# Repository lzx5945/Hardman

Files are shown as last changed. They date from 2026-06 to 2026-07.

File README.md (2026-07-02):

# Hardman
中国高校智能机器人创意赛主题三—轮式格斗机器人A类

代码以及PCB详情资料请见：https://github.com/lim668568-sketch/Robot_car_battle.git

📖一、总体设计理念

1.1 活动铲构型

采用 活动铲 替代传统固定铲，铲子可在出发时扬起，上台时利用惯性自然下落贴地。

该设计为内部部件（电机、电池、传感器等）释放出更大布置空间，同时保持整车尺寸为 27×29 cm，严格符合 A 类规则（≤30×30 cm）。

1.2 关节摩擦控制

铲臂转动处使用 轴承 + 自锁螺母 组合，精确调控摩擦力：

足够摩擦 → 铲子下落平稳不卡顿；

避免过紧 → 保证铲子能自由旋转，随地形自然贴合。

二、主体结构与材料策略

2.1 分层布局

层级	材料	作用

底盘	3mm 3K 碳纤维板	高刚性、低重心，提升行驶稳定性

上层顶板	玻璃纤维（等效铝材）	轻量化，同时保持足够刚度

非承力支架 & 上层建筑	3D 打印塑料	复杂结构易成型、成本低，显著控制整车质量

2.2 空间与传感器布置

活动铲释放更多内部空间，本车相较往届 预留更多传感器安装位。

通过固定结构的巧妙配合，将传感器精确布置于最佳位置，并可调整安装角度，使各传感器发挥最大感知效能——这是本设计的结构创新点之一。



图中并未显示前后传感器安装方式 我们在上层版开槽利用铜柱固定传感器

三、关键细节与创新机构

3.1 轮毂设计

内凹外平 造型：内凹部分环绕保护联轴器，抵御侧向撞击；

配合 抱紧式联轴器，防止轮子径向与轴向滑脱；

轮齿采用 T 字型牙状花纹，浇筑后与胶皮形成强力咬合，保证轮体一体化。



3.2 双模浇筑胎皮系统

通过 两次分步浇筑，实现胎皮 内硬外软 的密度梯度：

内圈硬 → 保证轮子支撑性；

外圈软 → 增大触地面积，显著提升摩擦力。

该工艺兼顾了高速转向稳定性和爆发加速抓地力，为对抗提供可靠行走基础。



缺点；
传感器选型不是最优解 12V光电传感器的加入导致电路更加复杂 交错的电路板给结构空间的利用提出很大考验 同时重量大大提高 导致没能达成头重脚轻的效果 对抗时颇显吃力
读者改进时可以全部选用5v传感器 同时前铲适当改变形状并使用光固化材料或者金属 

🙏致谢：
感谢彤哥和刘同学 我们调车的日子是一段充满挑战但很值得回忆的幸福时光

📞联系方式

1357490299@qq.com
欢迎大家交流！

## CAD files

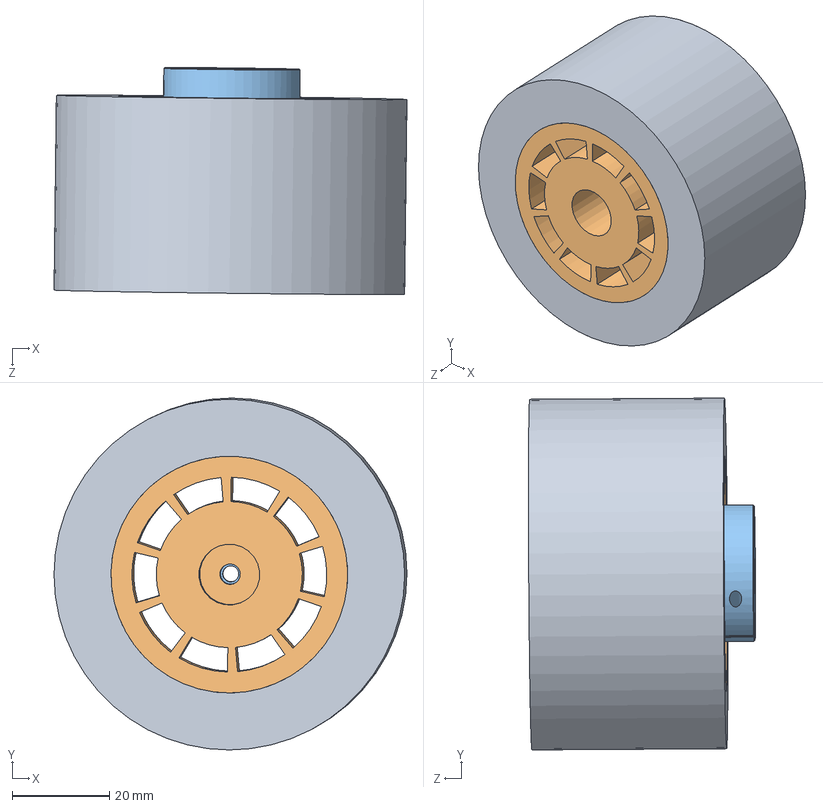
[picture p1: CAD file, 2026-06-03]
Wheel/Wheelhub/轮子装配抱紧式.SLDASM
72.5 x 72.2 x 46.6 mm
8mm抱紧式六角联轴器
抱紧式联轴器轮子
胎皮

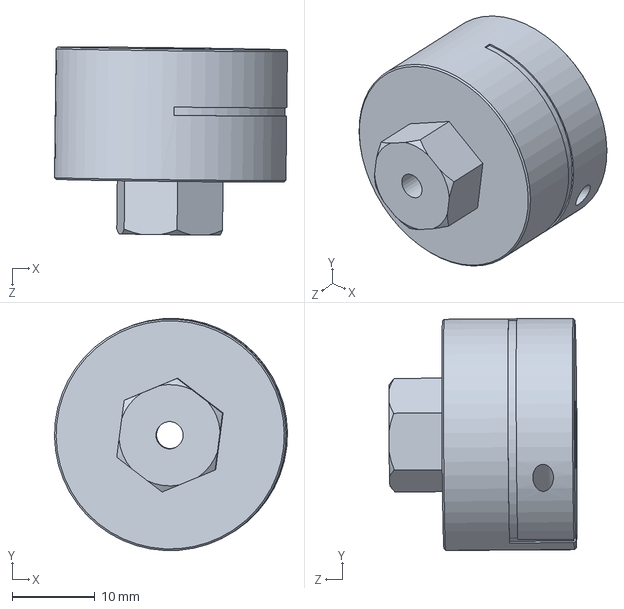
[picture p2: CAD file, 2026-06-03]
V2/轮子装配抱紧式.SLDASM
28.2 x 28.1 x 22.8 mm

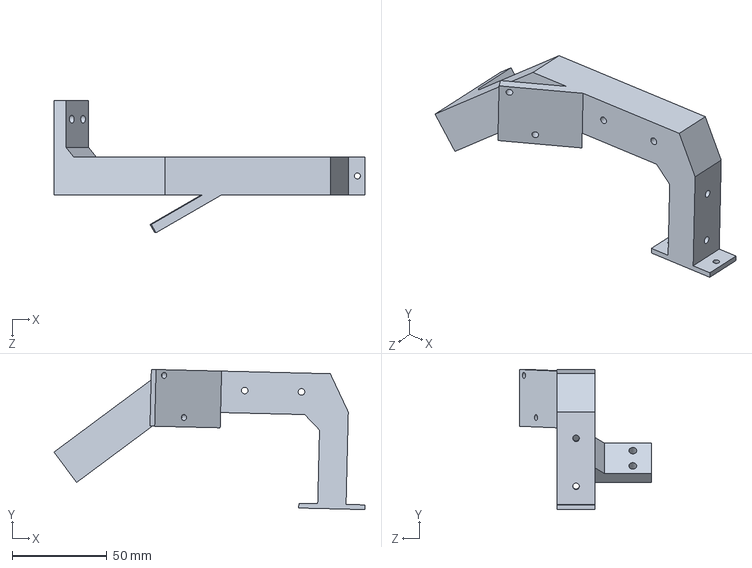
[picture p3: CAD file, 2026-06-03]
V2/支撑梁.SLDPRT
164.4 x 74.1 x 70.0 mm

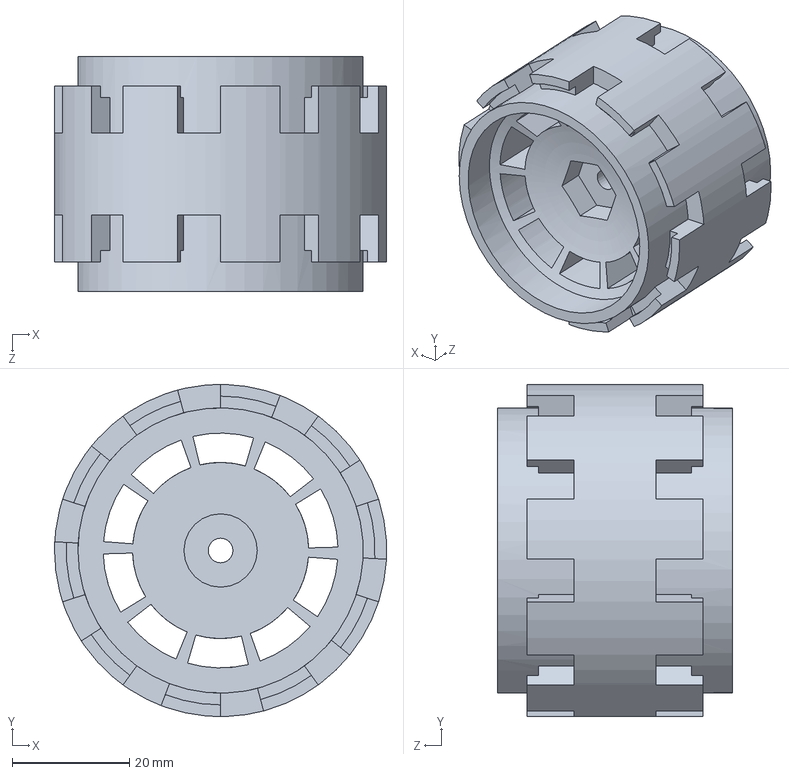
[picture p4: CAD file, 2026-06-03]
Wheel/Wheelhub/抱紧式联轴器轮子.SLDPRT
56.6 x 56.6 x 40.0 mm

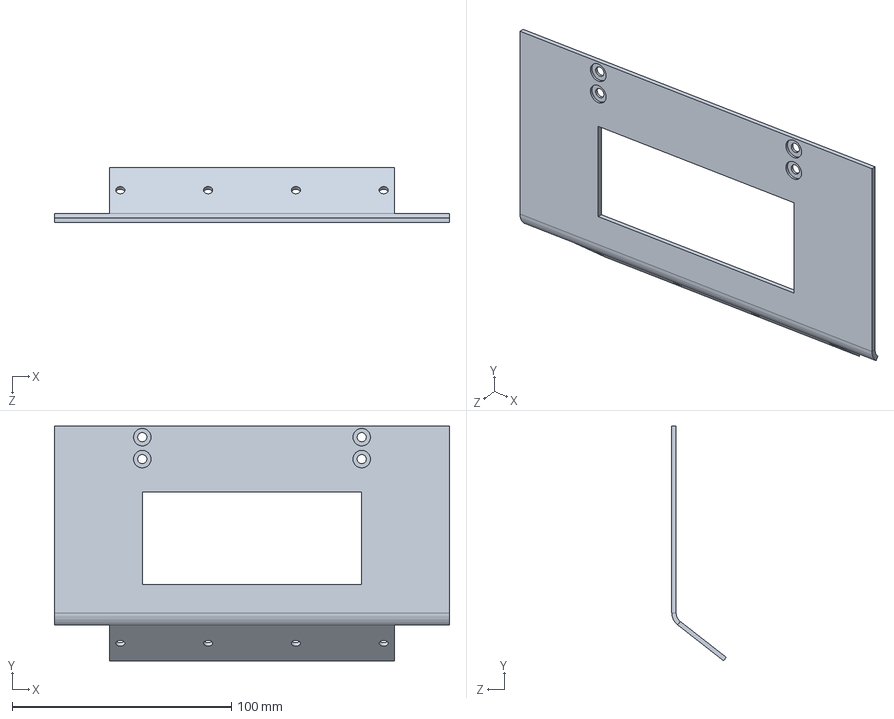
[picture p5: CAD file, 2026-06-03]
V2/上台系统V2.SLDPRT
180.0 x 106.9 x 24.9 mm

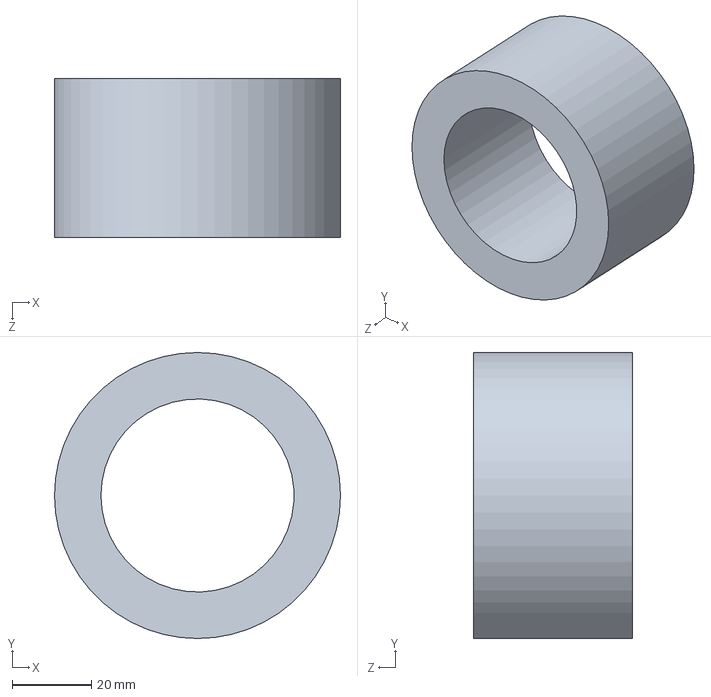
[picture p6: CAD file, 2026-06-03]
Wheel/GatingModel/胎皮.SLDPRT
72.0 x 72.0 x 40.0 mm

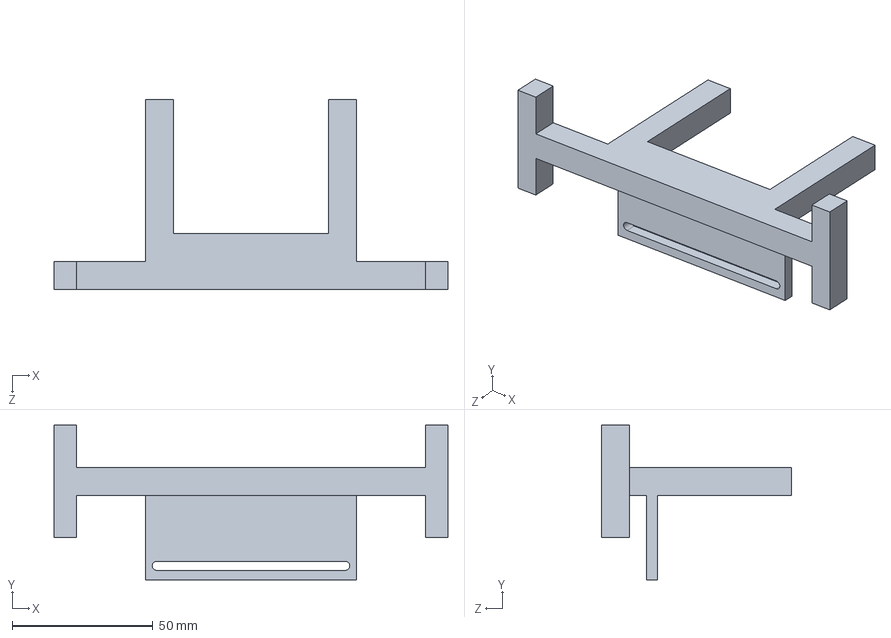
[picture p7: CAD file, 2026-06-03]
V2/摄像头支架.SLDPRT
140.0 x 55.0 x 67.6 mm

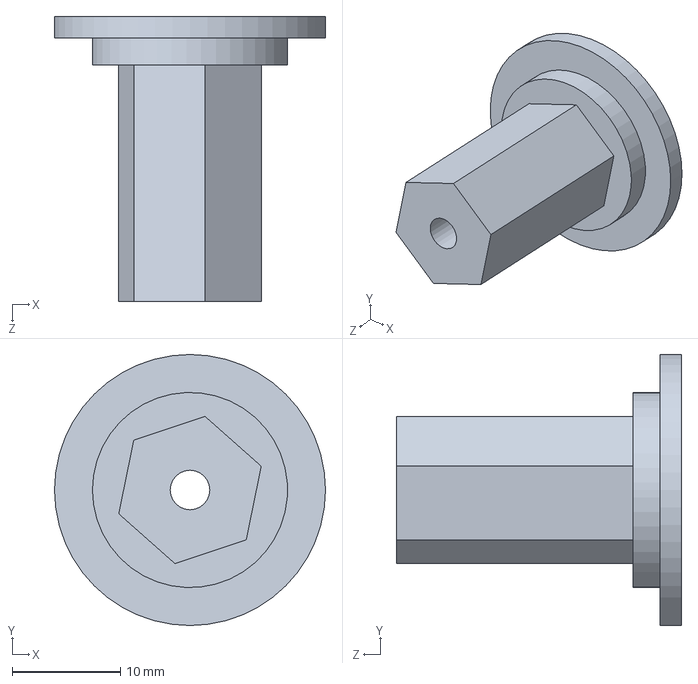
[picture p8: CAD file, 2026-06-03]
Wheel/GatingModel/六角柱.SLDPRT
25.0 x 25.0 x 26.3 mm

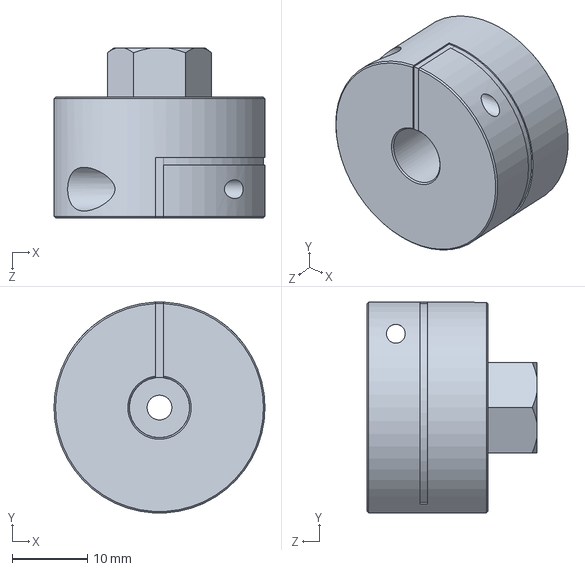
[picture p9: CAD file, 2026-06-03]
Wheel/Wheelhub/8mm抱紧式六角联轴器.SLDPRT
28.0 x 28.0 x 22.5 mm

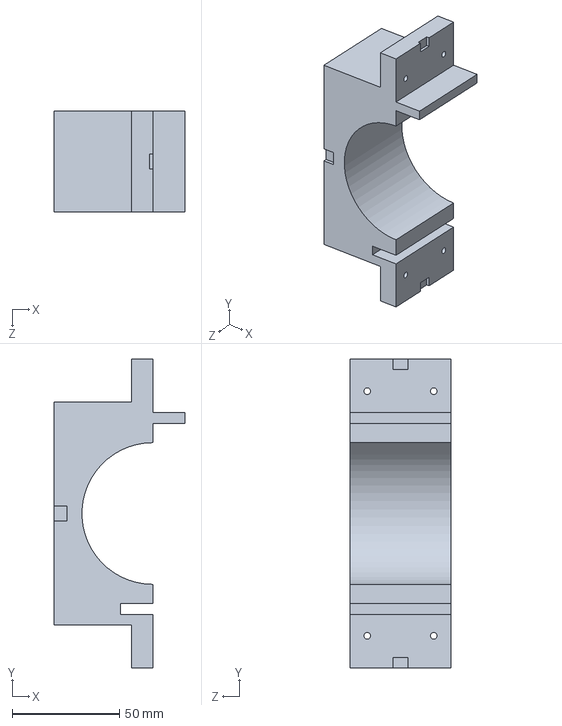
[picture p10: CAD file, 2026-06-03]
Wheel/GatingModel/浇筑侧壁66.SLDPRT
61.0 x 144.0 x 47.0 mm

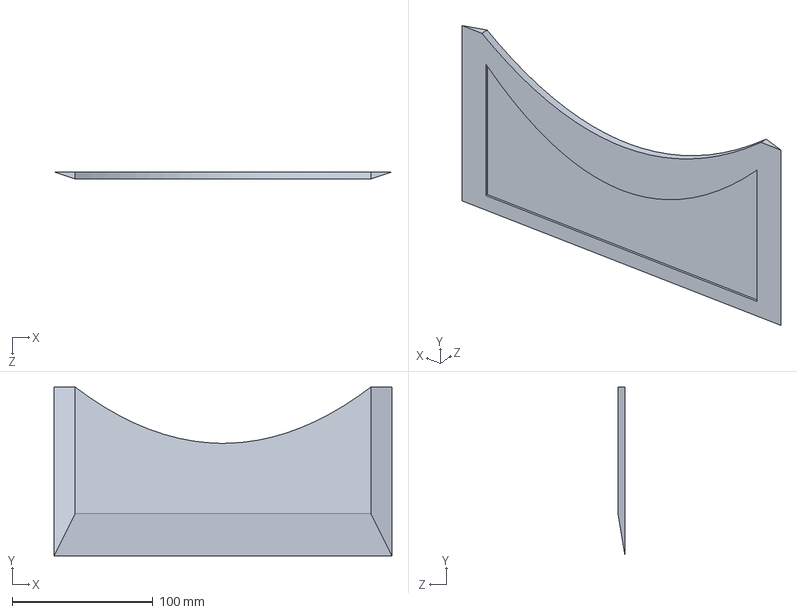
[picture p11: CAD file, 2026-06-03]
V2/铲刃.SLDPRT
240.0 x 120.0 x 5.00 mm

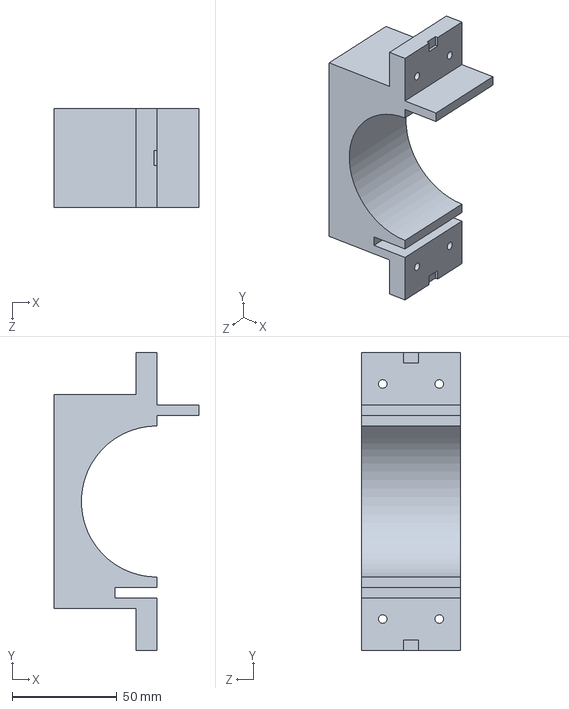
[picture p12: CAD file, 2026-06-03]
Wheel/GatingModel/浇筑侧壁72.SLDPRT
69.0 x 142.0 x 47.0 mm

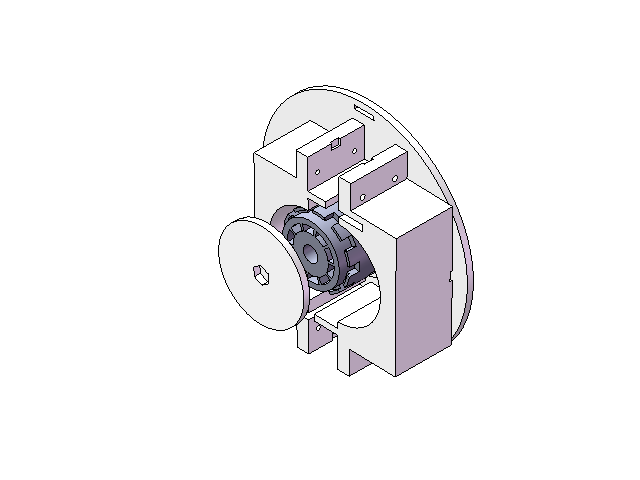
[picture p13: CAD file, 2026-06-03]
Wheel/GatingModel/浇筑装配.SLDASM
抱紧式联轴器轮子
浇筑侧壁66
浇筑侧壁72
浇筑底盘3.0
浇筑二层72
浇筑一层66
六角柱

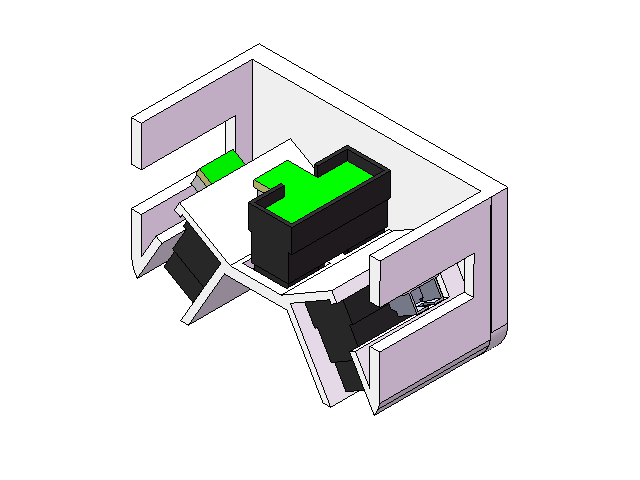
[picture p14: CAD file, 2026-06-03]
V2/红外测距装配.SLDASM
红外
红外测距传感器 x 3

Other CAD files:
V2/无刷马达.SLDASM
Wheel/GatingModel/轮子装配抱紧式.SLDASM
V2/摄像头装配.SLDASM
V1/32系新减速箱.SLDPRT
V1/32系新减速箱.STEP
V1/M36系电机支架-新.STEP
V1/S2412有刷电调（简装外壳）.STEP
V1/batman1.5.SLDASM
V1/bat轴承座.SLDPRT
V1/上台系统加厚版.SLDPRT
V1/上顶板1.5（适配bat1.5）.SLDPRT
V1/侧壁.SLDPRT
V1/底板2.0.SLDPRT
V1/抱紧式联轴器轮子.SLDPRT
V1/摄像头固定架.SLDPRT
V1/摄像头支撑架装配.SLDASM
V1/支撑一体化改良.SLDPRT
V1/方形红外光电.SLDPRT
V1/灰度传感器.SLDPRT
V1/电池bat.SLDPRT
V1/电池垫.SLDPRT
V1/红外侧支架bat1.5.SLDPRT
V1/装配体支架.SLDPRT
V1/轮子装配抱紧式.SLDASM
V1/铲子装配图bat.SLDASM
V2/1.SLDPRT
V2/2.SLDPRT
V2/3.SLDPRT
V2/4.SLDPRT
V2/5.SLDPRT
V2/6.SLDPRT
V2/7.SLDPRT
V2/8.SLDPRT
V2/9.SLDPRT
V2/K230.SLDPRT
V2/M36系电机支架-新.STEP
V2/MACHNE.SLDPRT
V2/上层版V2.SLDPRT
V2/减速箱.SLDPRT
V2/应力轴.SLDPRT
V2/底板V2.SLDPRT
V2/抱紧式联轴器轮子.SLDPRT
V2/支撑梁2.SLDPRT
V2/方形红外光电.SLDPRT
V2/电池27100.SLDPRT
V2/红外.SLDPRT
V2/红外测距传感器.SLDPRT
V2/装配体支架.SLDPRT
V2/轴承座.SLDPRT
V2/铲1.SLDPRT
V2/降压四路.SLDPRT
Wheel/GatingModel/浇筑一层66.SLDPRT
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

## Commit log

2026-06-03 6.3大区赛结束第一次上传
    [1.SLDPRT, 2.SLDPRT, 3.SLDPRT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]
2026-06-03 6.3大区赛结束后第一次提交
    [1.SLDPRT, 2.SLDPRT, 3.SLDPRT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]
2026-07-02 Expand README with design and innovation details
    Added detailed design concepts, materials strategy, and key innovations for the robot.
